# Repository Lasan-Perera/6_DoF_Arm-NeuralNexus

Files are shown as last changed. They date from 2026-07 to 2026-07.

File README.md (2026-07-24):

<div align="center">

# 🦾 NeuralNexus Arm

### A 6-DOF robotic arm built from scratch — mechanics, firmware, kinematics, and a live digital twin.














</div>

---

## 📑 Table of Contents

| # | Section |
|---|---|
| 1 | [Motor Selection](#1--motor-selection) |
| 2 | [Motors, Gearing, Speeds & Joints](#2--motors-gearing-speeds--joints) |
| 3 | [Simulation, IK & Path Planning](#3--simulation-ik--path-planning) |
| 4 | [Mechanical & Electrical Challenges](#4--mechanical--electrical-challenges) |
| 5 | [Hardware Stack](#5--hardware-stack) |
| ➕ | [Software Architecture](#-software-architecture) · [Control Panel](#-web-control-panel) · [Quick Start](#-quick-start) · [Roadmap](#-roadmap) |

---

## 🎯 What This Is

A fully custom 6-axis robotic arm — **not a kit**. Every layer was designed, debugged, and integrated in-house:

```
CAD (SolidWorks)  →  Simscape Multibody twin  →  Inverse Kinematics solver
                                ↓
                     USB CDC @ 115200 baud
                                ↓
              STM32H743 @ 420 MHz  →  6 stepper axes + gripper
                                ↓
                  AS5047P absolute encoders (SPI feedback)
```

**The headline feature:** a single command drives the **physical arm and the 3D digital twin simultaneously**, in sync, in real time.

---

### 🎥 Demos







 
---

## 1. 🔧 Motor Selection

Motor choice was driven by one principle: **torque scales with how much arm you're carrying.** The base carries everything; the wrist carries almost nothing. So the arm uses a *tiered* motor strategy rather than six identical motors.

### Selection Logic

```mermaid
graph TD
    A[Joint torque requirement] --> B{Carries how much<br/>downstream mass?}
    B -->|Base + all links| C[NEMA 23/24<br/>High torque]
    B -->|Wrist only| D[NEMA 17<br/>Low torque, compact]
    C --> E{Positional risk<br/>if steps lost?}
    E -->|Severe| F[Closed-loop driver<br/>CL57T]
    E -->|Moderate| G[Open-loop driver<br/>DM542]
    D --> H[Onboard TMC2209<br/>silent, microstepping]
```

### Why Each Choice

| Tier | Joints | Motor | Reasoning |
|:-----|:---|:---|:---|
| **Heavy** | J2, J3 | **NEMA 24** | Shoulder & elbow lift the entire outboard arm at maximum lever arm. Highest torque demand in the system. |
| **Medium** | J1 | **NEMA 23** | Base rotation carries full mass but works against *inertia*, not gravity — lower continuous torque than the lifting joints. |
| **Light** | J4, J5, J6 | **NEMA 17** | Wrist joints position only the end-effector. Compact size matters more than torque — mass here penalises every joint below it. |

> 💡 **Design insight:** every gram added at the wrist is a gram J2 and J3 must lift at full extension. Motor *mass* is a design constraint, not just torque.

### Driver Pairing

| Driver | Joints | Type | Why |
|:---|:---|:-----|:----|
| **CL57T** | J2, J3 | Closed-loop | Missed steps on the lifting joints = the arm silently drops. Closed-loop drivers detect and correct stalls internally. |
| **DM542** | J1 | Open-loop | Base rotation is more forgiving — a lost step is a heading error, not a collapse. |
| **TMC2209** | J4, J5, J6 | Onboard, silent | Integrated on the custom PCB. Quiet operation, fine microstepping, no external driver boxes for the wrist. |

---

## 2. ⚙️ Motors, Gearing, Speeds & Joints

### Full Drivetrain Map

| Joint | Role | Motor Slot | Motor | Driver | Signal Type | Gear Ratio | Pulses / Joint Rev |
|:---|:-----|:---|:---|:---|:---|:---|:---|
| **J1** | Base rotation | M6 | NEMA 23 | DM542 | Open-drain | **1 : 7** | 2800 |
| **J2** | Shoulder | M4 | NEMA 24 | CL57T | Open-drain | **1 : 30** | 5000 |
| **J3** | Elbow | M5 | NEMA 24 | CL57T | Open-drain | **1 : 30** | 5000 |
| **J4** | Wrist pitch | M2 | NEMA 17 | TMC2209 | Push-pull | **1 : 1** | 6400 |
| **J5** | Wrist roll | M1 | NEMA 17 | TMC2209 | Push-pull | **1 : 1** | 1600 |
| **J6** | End-effector | M3 | NEMA 17 | TMC2209 | Push-pull | **1 : 1** | 1600 |

> ⚠️ **Joints are NOT wired in motor order.** The joint→motor mapping is `jointToMotor[6] = {5, 3, 4, 1, 0, 2}`. This is baked into firmware so every layer above it can think in clean joint numbers (J1…J6, base→tip).

### J2 / J3 Compound Drivetrain

The two lifting joints use a **two-stage reduction** — and where the encoder sits inside that chain turns out to matter enormously (see §4):

```
Motor ──[ 1:10 planetary gearbox ]──► ENCODER ──[ 1:3 belt/pulley ]──► Joint
                                        ▲
                              magnet mounted HERE
                         (3 encoder turns per joint turn)
```

### Joint Limits & Reference Pose

| Joint | Min (°) | Max (°) | Range | Stable Pose (°) | Notes |
|:---|---:|---:|---:|---:|:---|
| J1 | −180 | +180 | 360° | 0 | Full rotation |
| J2 | −70 | +70 | 140° | −5 | Gravity-limited |
| J3 | **+120** | +240 | 120° | **120** | ⚠️ Starts *at* its lower limit — can only move **up** |
| J4 | −180 | +180 | 360° | 0 | Full rotation |
| J5 | +60 | +300 | 240° | 160 | 180°-centred band |
| J6 | −180 | +180 | 360° | 0 | Full rotation |

**Stable reference pose:** `[0, −5, 120, 0, 160, 0]` — the hand-matched starting configuration that keeps the physical arm and the simulation aligned for all relative motion.

### Motion Control Parameters

<table>
<tr><td><b>Control loop</b></td><td>TIM6 ISR @ <b>2 kHz</b> (PSC 74, ARR 499)</td></tr>
<tr><td><b>Tick period</b></td><td>500 µs</td></tr>
<tr><td><b>Max step rate</b></td><td>2000 steps/s (1 step per tick — hard ceiling)</td></tr>
<tr><td><b>Working speed</b></td><td>400 steps/s per joint</td></tr>
<tr><td><b>Acceleration</b></td><td>150 steps/s²</td></tr>
<tr><td><b>Profile</b></td><td>Trapezoidal ramp with decel-to-stop lookahead</td></tr>
</table>

### The Motion Profile

Every axis runs a non-blocking trapezoidal velocity profile inside the ISR — accelerate, cruise, decelerate — computed independently per joint:

```
speed
  ▲
  │     ┌─────────────────┐
  │    ╱                   ╲
  │   ╱                     ╲
  │  ╱                       ╲
  └─┴─────────────────────────┴──► time
    accel        cruise      decel
         (stepsToStop lookahead)
```

> 📐 **The scaling trap:** when the ISR was retuned from 50 kHz → 2 kHz, the hardcoded constants `dt = 0.00002` and `stepInterval = 50000/speed` were **25× wrong**, making every motor crawl. Correct values: `dt = 0.0005`, `stepInterval = 2000/speed`. Tick rate and motion math must always be changed together.

### Command Protocol

| Command | Format | Example | Action |
|:---|:---|:---|:---|
| **Joint move** | 6 comma-separated degrees | `0,-50,60,-80,-90,50` | Relative move on all six joints |
| **Gripper** | `G,<0\|1>` | `G,1` | Open / close servo |
| **Home** | `HOME` | `HOME` | Encoder-based homing (J4/J5/J6) |
| **Test** | `TEST` | `TEST` | 30° encoder calibration measurement |

---

## 3. 🧠 Simulation, IK & Path Planning

### Pipeline

```mermaid
flowchart LR
    A[SolidWorks CAD] -->|export| B[Simscape Multibody]
    B -->|importrobot| C[rigidBodyTree]
    C --> D[inverseKinematics solver]
    E[Target XYZ + orientation] --> D
    D --> F[6 joint angles]
    F --> G[Quintic blend<br/>trajectory]
    G --> H[Mechanics Explorer<br/>3D twin]
    G --> I[USB CDC → STM32<br/>physical arm]
    style H fill:#0076A8,color:#fff
    style I fill:#03234B,color:#fff
```

### Kinematic Model

The CAD assembly exports directly into a **`rigidBodyTree`**, with real joint limits applied so the solver never proposes an unreachable pose:

```matlab
robot = importrobot('Assem1');
robot.DataFormat = 'row';
limitsDeg = [-180 180; -70 70; 120 240; -180 180; 60 300; -180 180];
for i = 1:6
    robot.Bodies{i}.Joint.PositionLimits = deg2rad(limitsDeg(i,:));
end
ik = inverseKinematics('RigidBodyTree', robot);
```

### Trajectory Generation

Paths are interpolated with a **quintic (5th-order) blend** rather than linear interpolation — this gives zero velocity *and* zero acceleration at both endpoints, so motion starts and stops smoothly instead of jerking:

```matlab
b = (k-1)/(steps-1);
blend = 10*b^3 - 15*b^4 + 6*b^5;   % smoothstep: S-curve, C² continuous
pose = startPose + (targetPose - startPose) * blend;
```

### Planned Paths & Demos

| Demo | What It Proves | Method |
|:-----|:---|:---|
| 🎯 **Position Lock** | Tip holds a fixed point in space while the arm reconfigures around it | IK solved for constant XYZ, sweeping orientation |
| 🧭 **Orientation Lock** | Tool orientation stays fixed while the tip sweeps X, then Y, then Z | IK solved for constant rotation matrix, moving XYZ |
| ⬜ **Vertical Square** | Coordinated multi-joint straight-line tracing | 4 corners in the Y–Z plane, edges interpolated, IK per point |
| 👋 **Bye Wave** | Balanced choreography that returns exactly to start | Hand-tuned deltas, every joint column sums to zero |
| 🤖 **Pick & Place** | Full task sequence with gripper actuation | Recorded relative poses + `G,0` / `G,1` |

> 🔬 **A fundamental result we proved (and had to design around):**
>
> **A 6-DOF arm cannot hold tip position AND tool orientation fixed simultaneously while the links reconfigure.** That needs a 7th degree of freedom. Six DOF = exactly six constraints = a unique solution with no redundancy left to exploit. Every "lock" demo therefore locks *one* constraint and varies the other. This wasn't a bug — it's the kinematics telling us the truth.

### Synchronised Twin

The `moveBoth()` function is the centrepiece — one call, two arms:

```matlab
moveBoth(s, [0 10 0 0 0 0])   % J2 +10° on BOTH the real arm and the simulation
```

It tracks accumulated pose in a persistent variable, runs a soft-limit check before committing, streams the delta over serial, and animates the Simscape model — all from a single command.

---

## 4. 🔥 Mechanical & Electrical Challenges

> *This is the section that actually took the time.* Every entry below cost hours of debugging and is documented so it never has to be rediscovered.

### 🥇 The Big One: Phantom Encoder Wander

**Symptom:** encoder readings on a *stationary* joint appeared to swing by **60–70°** between samples. Completely unusable for absolute positioning.

**Failed hypotheses** (each cost a debugging cycle):

| Theory | Test | Result |
|:---|:-----|:---|
| SPI too fast → signal integrity | Slowed prescaler 32 → 64 | Slightly better |
| Still too fast | Slowed further → 128 | ❌ **Got WORSE** |
| ISR corrupting SPI mid-frame | Moved reads to main loop | ❌ No change |

**Actual root cause:** the read function returns **`−1` on a failed read**, and those `−1` sentinels were being **averaged in with valid readings**. A few error codes in a 30-sample mean dragged the average wildly. The sensor was perfect the whole time.

**Fix:** filter `−1` before averaging.

```matlab
if row(j) >= 0            % ← the entire fix
    sums(j) = sums(j) + row(j);
    counts(j) = counts(j) + 1;
end
```

**Result:** readings repeatable to **±0.01°** across runs.

```
BEFORE (raw mean):  J4 = 310.40 → 274.49 → 346.27    (±72° spread) ❌
AFTER  (filtered):  J4 = 181.88 → 181.88 → 181.88    (±0.01°)      ✅
```

> 🧠 **The lesson:** *"slowing it down made it worse"* was the decisive clue. A genuine signal-integrity problem always improves with a slower clock. When it didn't, the problem was never analogue — it was a data-hygiene bug in software.

---

### ⚡ Electrical Failures

<table>
<tr><th align="left">Failure</th><th align="left">Cause</th><th align="left">Resolution</th></tr>
<tr>
<td>💀 <b>3 GPIO pins destroyed</b><br/><code>PE0</code>, <code>PD7</code>, <code>PD3</code></td>
<td>5 V back-feed during miswired open-drain testing — external pull-ups fed 5 V into 3.3 V-tolerant-only pins</td>
<td>Remapped in <code>.ioc</code> → <code>PE7</code>, <code>PD11</code>, <code>PD12</code>. Dead pins left unassigned (Hi-Z). One bodge wire via the <code>M3_MS1</code> pad.</td>
</tr>
<tr>
<td>💀 <b>LDO destroyed</b><br/><code>ST1L05CPU33R</code> (3.3 V rail)</td>
<td>Failed on connection to the main electronics compartment — suspected input overvoltage, inductive transient from the steppers, or insufficient local decoupling</td>
<td><b>Open.</b> Measure actual V<sub>IN</sub> at the LDO footprint <i>before</i> fitting a replacement.</td>
</tr>
</table>

---

### 🔌 The Driver Topology Trap

The custom PCB mixes **two electrically incompatible driver families**, and getting the GPIO mode wrong produces a *silent* failure — no error, the motor just doesn't move.

| | J4 / J5 / J6 (TMC2209) | J1 / J2 / J3 (CL57T · DM542) |
|:--|:--|:--|
| **Mounting** | Onboard | External boxes |
| **GPIO mode** | `OUTPUT_PP` (push-pull 3.3 V) | `OUTPUT_OD` (open-drain) |
| **Wiring** | Direct logic | Common-anode via optocoupler |
| **Enable** | `SetEnableM1M2M3(true)` → LOW | `SetEnableM4M5M6(false)` → **HIGH** |

> ⚠️ **Counter-intuitive but correct:** `Stepper_SetEnableM4M5M6(false)` is what **enables** the external drivers. With common-anode wiring, driving the open-drain pin HIGH releases it (Hi-Z) → opto LED dark → drivers enabled. This looks like a bug in code review. **It is not. Do not "fix" it.**

---

### 🐛 Firmware Bugs Worth Remembering

<details>
<summary><b>Double direction handling</b> — homing only converged from one side</summary>

`Stepper_MoveAllJoints()` applies `jointDir[]` internally. The homing routine *also* computed direction from the measured `encStepSign`. Two sign flips = they cancelled on one side of the target and doubled on the other.

**Fix:** homing and encoder-driven motion must use `Stepper_MoveAll()` — the raw, motor-indexed mover with **no** `jointDir` applied.
</details>

<details>
<summary><b>The unreachable gripper branch</b> — <code>G,0</code> silently did nothing</summary>

```c
if (rxFlag) {
    rxFlag = 0;                    // ← cleared here
    ...
    else if (rxFlag) {             // ← always FALSE. Dead branch.
        if (rxTemp[0] == 'G') { Gripper_Open(); }   // never reached
    }
}
```

The gripper worked perfectly when called directly from the loop — which proved the hardware was fine and pointed straight at command dispatch.

**Fix:** flatten the handler; make the gripper check a top-level `else if`.
</details>

<details>
<summary><b>Off-by-one on joint index</b> — J6 refused to home</summary>

`uint8_t j = 6;` — but joints are indexed **0–5**. J6 is index **5**. Every array access (`homeAngle[6]`, `motors[6]`, `js[6]`) read past the end of its array — undefined behaviour that happened to produce silence instead of a crash.
</details>

<details>
<summary><b>Two infinite loops</b> — commands ignored while encoders streamed</summary>

A leftover `while(1)` encoder-print loop sat *above* the main loop, trapping the CPU forever. The command handler below it was never reached. Symptom looked like "the arm reads encoders but ignores serial" — actually the CPU never got there.
</details>

<details>
<summary><b>Serial handshake deadlock</b> — MATLAB froze mid-demo</summary>

A periodic `enc |` status print flooded the serial line, so MATLAB's `readline() == "END"` handshake never matched → infinite wait, sim and arm both frozen.

**Fix:** telemetry streaming and command handshaking cannot share one wire. Pick one mode at a time, or make the reader tolerant with a timeout.
</details>

---

### ⏱️ The Timing Discovery

**Symptom:** commanding 60° produced only ~30° of motion. Increasing the amplitude didn't help.

**Measurement:** a 60° move physically takes **~4 seconds** at 400 steps/s. The demo scripts were sending the next command after **1 second** — every move was being interrupted at ~25% completion and replaced with a fresh target.

**Solution (user-devised):** never send a move larger than **10°**. Split a 60° move into six 10° commands, each of which completes comfortably within the 1 s window.

```matlab
nChunks   = ceil(max(abs(delta)) / 10);
stepDelta = delta / nChunks;
for c = 1:nChunks
    writeline(s, sprintf('%.2f,%.2f,%.2f,%.2f,%.2f,%.2f', stepDelta));
    pause(1.0);
end
```

> ✅ Elegant because it needs **no firmware change and no handshake** — it just respects the physics of how long a move actually takes.

---

### 🔩 Mechanical: The Simscape Over-Constraint

The imported model wouldn't move at all. Cause: **over-constrained SolidWorks mates**.

| Problem | Effect |
|:---|:---|
| Extra Parallel / Perpendicular mates | Collapsed revolute joints into rigid welds — zero DOF |
| Base mated to non-adjacent links | Created closed kinematic loops the solver couldn't resolve |

**Rule established:** exactly **one concentric + one coincident/distance** mate per joint. Nothing more. Clean serial chain: `Base → P1 → P2 → P3 → P4 → P5 → EndEffector`.

---

### 🧲 The Encoder Mounting Constraint

The most consequential *mechanical* decision in the project — and it was discovered after the fact.

An AS5047P is absolute over **one magnet revolution**. Whether a joint can determine its own position at power-on depends entirely on **what gearing remains between the magnet and the joint**:

```mermaid
graph LR
    A[Encoder magnet] -->|remaining ratio 1:1| B[✅ TRUE ABSOLUTE<br/>one unique reading]
    A -->|remaining ratio 1:N| C[❌ N-fold ambiguity<br/>N poses share a reading]
```

| Joint | Ratio *after* encoder | Absolute on boot? | Consequence |
|:---|:---|:---|:---|
| J1 | 1 : 7 | ❌ | 7 candidate positions per reading |
| J2 | 1 : 3 | ❌ | 3 candidates |
| J3 | 1 : 3 | ❌ | 3 candidates |
| **J4** | **1 : 1** | ✅ | Unique — true absolute |
| **J5** | **1 : 1** | ✅ | Unique — true absolute |
| **J6** | **1 : 1** | ✅ | Unique — true absolute |

**Workaround in use:** hand-position the arm *roughly* near home, then command `HOME`. Pre-positioning within one encoder revolution removes the ambiguity entirely, letting the encoder resolve the fine error. Clever, free, and it works today.

**Permanent fix (future revision):** relocate the J1/J2/J3 magnets to the *joint side* of the final reduction. All six joints then become absolute and the whole problem disappears.

---

### 💻 Host-Side Gotchas

| Issue | Symptom | Fix |
|:---|:---|:----|
| **USB CDC won't enumerate** | Device Manager shows nothing / "Unknown Device" | Route **HSI48** to USB clock + call `HAL_PWREx_EnableUSBVoltageDetector()` **before** `MX_USB_DEVICE_Init()` |
| **Board freezes at boot** | No LED, no USB, totally dead | `MX_SDMMC1_SD_Init()` traps in `Error_Handler()` with no SD card. Keep SDMMC1 + FATFS **disabled in the `.ioc`** |
| **COM port keeps changing** | COM9 → COM12 → COM14… | Windows caches stale USB devices. Device Manager → *Show hidden devices* → uninstall greyed entries → replug |
| **`importrobot` fails** | "Variable `jointData` has been deleted" | Simscape *From Workspace* blocks are evaluated during import. Run `jointData = zeros(2,7);` **first** |
| **Timer resource conflict** | Gripper twitched whenever the buzzer sounded | Both were on TIM2. `Buzzer_SetFreq()` reprograms PSC/ARR, destroying the servo's 50 Hz frame. **Moved gripper to TIM1_CH3** — conflict eliminated |

---

## 5. 🛠️ Hardware Stack

### Compute

| Component | Spec |
|:---|:-----|
| **MCU** | STM32H743VITx, Cortex-M7 |
| **Clock** | 420 MHz (25 MHz HSE → PLL) |
| **PCB** | Custom board (migrated from WeAct MiniSTM32H743 dev board) |
| **Toolchain** | STM32CubeIDE + CubeMX (HAL) |

### Actuation

| Component | Detail |
|:---|:---|
| **Steppers** | 2× NEMA 24 · 1× NEMA 23 · 3× NEMA 17 |
| **Closed-loop drivers** | 2× CL57T (J2, J3) |
| **Open-loop driver** | 1× DM542 (J1) |
| **Onboard drivers** | 3× TMC2209 (J4, J5, J6) |
| **Gripper** | Hobby servo · TIM1_CH3 · 50 Hz PWM · 930 µs open / 1100 µs close |

### Sensing

| Component | Detail |
|:---|:---|
| **Encoders** | 6× AS5047P magnetic absolute, 14-bit (16384 counts/rev) |
| **Bus** | SPI1 — 16-bit frames, CPOL HIGH / CPHA 2EDGE (mode 1) |
| **Chip selects** | `PB0` `PB1` `PB2` `PC7` `PC6` `PD15` (active-LOW) |
| **Noise floor** | ±0.04° at rest (after `−1` filtering) |

### Peripherals & I/O

| Function | Resource |
|:---|:---|
| Stepper control loop | TIM6 @ 2 kHz interrupt |
| Gripper servo PWM | TIM1_CH3 |
| Buzzer | TIM2_CH2 / PA1 |
| Host link | USB CDC Virtual COM @ 115200 |
| Status | Onboard LED, user buttons |

### Peripheral Allocation

```
TIM1 ─── CH3 ──► Gripper servo PWM (50 Hz)
TIM2 ─── CH2 ──► Buzzer (variable frequency)
TIM6 ─────────► Stepper ISR @ 2 kHz  ◄── the heartbeat
SPI1 ─────────► AS5047P encoder chain ×6
USB  ─────────► CDC Virtual COM Port
```

> 🧯 **Peripheral conflicts are real.** The gripper and buzzer originally shared TIM2 and were mutually exclusive — playing a tone corrupted the servo signal. Separating them onto different timers was a genuine architectural fix, not cosmetic.

---

## 🏗️ Software Architecture

```mermaid
graph TB
    subgraph HOST["🖥️ Host Layer"]
        M[MATLAB<br/>IK · Simscape twin]
        W[Web Control Panel<br/>Web Serial API]
    end
    subgraph FW["⚙️ STM32 Firmware"]
        P[Command Parser]
        S[Stepper_MoveAllJoints<br/>joint-indexed + jointDir]
        R[Stepper_MoveAll<br/>raw motor-indexed]
        I[TIM6 ISR @ 2 kHz<br/>trapezoidal profile]
        E[Encoder read + tick accumulate]
        H[Home_All · Encoder_Test30]
    end
    subgraph HW["🦾 Hardware"]
        D[6× Stepper drivers]
        G[Gripper servo]
        A[6× AS5047P]
    end
    M -->|USB CDC| P
    W -->|USB CDC| P
    P --> S
    P --> G
    P --> H
    H --> R
    S --> I
    R --> I
    I --> D
    I --> E
    A --> E
    E --> H
    style I fill:#c62828,color:#fff
    style M fill:#0076A8,color:#fff
    style W fill:#f7df1e,color:#000
```

### Two Movers, One Critical Distinction

| Function | Indexing | Applies `jointDir`? | Use for |
|:---|:---|:---|:---|
| `Stepper_MoveAllJoints()` | **Joint** (J1…J6) | ✅ Yes | Commands from MATLAB / UI |
| `Stepper_MoveAll()` | **Motor** (M1…M6) | ❌ No | Homing & encoder-driven correction |

> ☝️ Mixing these up causes the **double-direction bug** — the single most time-consuming class of error in this project. Encoder feedback already knows the true physical direction via `encStepSign`; applying `jointDir` on top of it inverts the correction on one side of the target.

---

## 🎛️ Web Control Panel

A standalone **Web Serial** control panel that talks to the arm directly — **no MATLAB, no Python, no install.** Just open the HTML file in Chrome or Edge.

```
┌──────────────────────────────────────────────┐
│ 🔌 Connect arm      ● Connected       ■ Stop │
├──────────────────────────────────────────────┤
│  RECORDED SEQUENCES               Delay [4]s │
│  ┌──────────┬──────────┬───────────────────┐ │
│  │ Show off │   Pick   │ Place from pole   │ │
│  ├──────────┼──────────┴───────────────────┤ │
│  │Pick pole │  Pick and place pole         │ │
│  └──────────┴──────────────────────────────┘ │
├──────────────────────────────────────────────┤
│  JOINT CONTROL — relative move               │
│  J1 ─────────────●─────────────   0°         │
│  J2 ─────────────●─────────────   0°         │
│  J3 ─────────────●─────────────   0°    …    │
│           [ Send move ]   [ Reset ]          │
├──────────────────────────────────────────────┤
│  [ Open ]   [ Close ]   [ Home ]             │
│  > 0,-50,60,-80,-90,50            [ Send ]   │
└──────────────────────────────────────────────┘
```

| Feature | Detail |
|:---|:---|
| **Transport** | Web Serial API @ 115200 — direct browser-to-MCU |
| **Sequences** | All five recorded motions as one-click buttons |
| **Jog control** | Six centred sliders (−90° … +90°), sent as one relative move |
| **Safety** | Stop button cancels a running sequence mid-flight |
| **Live log** | Timestamped record of every command sent |

> 🌐 **Why this matters for a finished product:** the demo machine no longer needs a MATLAB licence. MATLAB remains the *authoring* environment (IK, trajectory design, the digital twin) — the browser is the *operator* interface.

---

## 🚀 Quick Start

### Firmware

```bash
# 1. Open the project in STM32CubeIDE
# 2. If regenerating from CubeMX, re-comment MX_SDMMC1_SD_Init()  ← it traps without an SD card
# 3. Build (🔨) and flash via ST-Link (▶)
# 4. Confirm the board enumerates as a USB Virtual COM Port
```

### MATLAB Session

```matlab
jointData = zeros(2,7);              % MUST come first — From Workspace blocks need it
load_system('Assem1');
robot = importrobot('Assem1');  robot.DataFormat = 'row';

limitsDeg = [-180 180; -70 70; 120 240; -180 180; 60 300; -180 180];
for i = 1:6
    robot.Bodies{i}.Joint.PositionLimits = deg2rad(limitsDeg(i,:));
end

ik = inverseKinematics('RigidBodyTree', robot);
weights = [1 1 1 1 1 1];
q0 = homeConfiguration(robot);
s  = serialport("COM9", 115200);     % update port as needed
```

### Everyday Commands

```matlab
armIK(robot, ik, weights, q0)                            % interactive IK slider tool
goToXYZ(robot, ik, weights, q0, [-0.15 0.30 0.10], s)    % XYZ → arm + synced twin
moveBoth(s, [0 10 0 0 0 0])                              % relative move on BOTH
armWave(s)                                               % goodbye choreography
objectPicking(s)                                         % pick sequence
writeline(s, "HOME")                                     % encoder homing
```

### Browser Panel

```
1. Close the MATLAB port first:  clear s
2. Open NeuralNexusArmControl.html in Chrome / Edge
3. Click "Connect arm" → select the COM port
4. Drive it.
```

---

## 📊 Project Status

| Subsystem | Status | Notes |
|:---|:---:|:---|
| 6-axis stepper control | ✅ | Trapezoidal profile, 2 kHz ISR |
| USB CDC command link | ✅ | 115200, parsed & verified |
| Joint mapping | ✅ | `jointToMotor` verified on hardware |
| Direction signs | ✅ | `jointDir` verified via A/B sim-vs-hardware |
| MATLAB IK pipeline | ✅ | `rigidBodyTree` + solver + limits |
| Synchronised digital twin | ✅ | `moveBoth()` — arm & sim in lockstep |
| Gripper servo | ✅ | TIM1_CH3, serial-commanded |
| Encoder read (AS5047P) | ✅ | ±0.01° repeatable after `−1` filtering |
| Recorded motion library | ✅ | 5 sequences + wave + square |
| Web control panel | ✅ | Web Serial, MATLAB-free |
| Homing — J4 / J5 / J6 | 🟡 | Works; scaling verification ongoing |
| Homing — J1 / J2 / J3 | 🔴 | Blocked by encoder mounting ratio |
| `pulsesPerJointRev` calibration | 🟡 | J6 measured at 3200 (not 1600) — others pending |
| Absolute positioning | 🟡 | Viable for the 1:1 wrist joints |
| 3.3 V LDO replacement | 🔴 | Measure V<sub>IN</sub> before fitting |
| Closed-loop step correction | ⚪ | Planned |
| Vision pick-and-place | ⚪ | Planned |

---

## 🗺️ Roadmap

```mermaid
gantt
    title Development Phases
    dateFormat X
    axisFormat %s
    section Complete
    Simscape model fix        :done, 0, 1
    MATLAB IK pipeline        :done, 1, 2
    STM32 6-axis firmware     :done, 2, 3
    Encoder integration       :done, 3, 4
    Synced twin and demos     :done, 4, 5
    Web control panel         :done, 5, 6
    section In Progress
    Per-joint calibration     :active, 6, 7
    Absolute positioning      :active, 7, 8
    section Planned
    Closed-loop correction    :8, 9
    Encoder remount J1-J3     :9, 10
    Vision pick-and-place     :10, 11
```
---

# 👁️ Computer Vision & Object Detection











> **The eyes of the NeuralNexusArm.** This subsystem turns raw camera pixels into real-world `(X, Y)` coordinates that feed straight into the inverse kinematics solver — closing the loop between *seeing* and *reaching*.

---

## 🔁 Pipeline Overview

```mermaid
flowchart LR
    A([📷 Camera Feed]) --> B[🧹 Undistort<br/>Camera + Distortion Matrix]
    B --> C{🎯 Detection Mode}
    C -->|Primary| D[🎨 OpenCV<br/>Colour Segmentation]
    C -->|Fallback| E[🧠 Trained Models<br/>YOLO / Custom]
    D --> F[📍 Object Centroid<br/>in pixels]
    E --> F
    F --> G[🗺️ Homography<br/>Pixel → World mm]
    G --> H([🦾 IK Solver → Arm Motion])

    style A fill:#1f77b4,stroke:#fff,color:#fff
    style D fill:#2ca02c,stroke:#fff,color:#fff
    style E fill:#9467bd,stroke:#fff,color:#fff
    style G fill:#ff7f0e,stroke:#fff,color:#fff
    style H fill:#d62728,stroke:#fff,color:#fff
```

---

## Object Detection

### Primary — OpenCV Colour Identification

The main detection path uses **classical colour segmentation** (HSV thresholding → contour extraction → centroid).

Why classical over learned, as the default?

| Latency | Determinism | Compute | Tunability |
|:---:|:---:|:---:|:---:|
| Millisecond-scale | Same input → same output, every time | Runs comfortably on CPU | Live HSV slider tuning |

### Secondary — Trained Detectors

For objects that colour alone cannot separate, the repository also ships learned detectors:

| Model | Target | Type |
|---|---|:---:|
| 📦 Custom trained | Cardboard box detection |  |
| 🍬 Custom trained | Candy detection |  |
| `yolo26n.pt` | General-purpose objects |  |
| `yolo11n.pt` | General-purpose objects |  |

---

## Camera Calibration

Calibration runs in **two independent stages** — first fix the *camera*, then fix the *world*.

```mermaid
flowchart TB
    subgraph S1["🔬 Stage 1 — Intrinsic"]
        A1[♟️ 20 Chessboard Images] --> A2[Camera Matrix]
        A1 --> A3[Distortion Coefficients]
        A2 --> A4[✅ Reprojection Error<br/>0.6863 px]
        A3 --> A4
    end
    subgraph S2["🌍 Stage 2 — Extrinsic"]
        B1[📏 Fixed Mount @ 41 cm] --> B2[Known World Points]
        B2 --> B3[3×3 Homography Matrix]
        B3 --> B4[✅ Pixel → mm Mapping]
    end
    S1 --> S2

    style A4 fill:#2ca02c,stroke:#fff,color:#fff
    style B4 fill:#2ca02c,stroke:#fff,color:#fff
```

### ♟️ Stage 1 — Chessboard Calibration *(Intrinsic)*

Standard OpenCV chessboard calibration recovers two matrices:

<table>
<tr>
<td width="50%">

**🔭 Camera Matrix**

Describes the camera's *own* optical properties:
- Focal lengths `fx`, `fy`
- Principal point `cx`, `cy`

</td>
<td width="50%">

** Distortion Coefficients**

Model and cancel lens distortion:
- Radial (barrel / pincushion)
- Tangential (sensor misalignment)

</td>
</tr>
</table>

**Method** — 20 chessboard images captured at varying angles, orientations, and positions across the frame.

<!-- Rendered as a green "Tip" callout on GitHub -->
> [!TIP]
> **Result: mean reprojection error = `0.6863 px`** — comfortably sub-pixel, which is a healthy calibration for a 20-image set.

### Stage 2 — Homographic Calibration *(Pixel → World)*

With the camera **rigidly mounted at a fixed height**, a single `3×3` homography maps undistorted pixel coordinates to real-world planar coordinates in the arm's base frame.

Because the pose is fixed and every target lies on one plane (the table surface), **no per-frame depth estimation is required** — one matrix does the whole job.

```
┌─────────────────────────────────────────┐
│   📷  Camera                            │
│    │                                    │
│    │  ↕  Fixed height = 41 cm           │
│    │                                    │
│  ══╧══════════════════════════════════  │  ← Work surface (Z = 0)
│      🎯 Targets live on this plane      │
└─────────────────────────────────────────┘
```

<!-- Rendered as a red "Warning" callout on GitHub -->
> [!WARNING]
> The homography is valid **only** for this exact mounting height and pose. Move or re-aim the camera and the homographic calibration **must be redone** — the intrinsic calibration, however, stays valid.

---

<div align="center">

### 📂 Repositories




---
</div>

## 👥 Team
 
| Index No. | Name | GitHub |
|:---|:-----|:---|
| **230487D** | Lasan Perera | [@Lasan-Perera](https://github.com/Lasan-Perera) |
| **230502X** | Deneth Priyadarshana | — |
| **230492M** | Dulana Pitiwaduge | [@DulanaPiti](https://github.com/DulanaPiti) |
| **230051L** | Isitha Dinujaya | — |
| **230108U** | Mokshan Colombage | — |
 
---

<!-- ## License -->
<!-- Add a license here (e.g. MIT) if you want others to reuse the code. -->

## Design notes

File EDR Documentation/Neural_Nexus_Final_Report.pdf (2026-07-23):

University of Moratuwa: Electronic Design Realization

# NEURAL NEXUS

## Advanced 6-DOF Robotic & AI Ecosystems for Precision Automation

### Team Neural Nexus

### Lasan Perera 230487D Isitha Dinujaya 230051L Deneth Priyadarshana 230502X Dulana Pitiwaduge 230492M Mokshan Colombage 230018U

### July 19, 2026

Abstract

The global industrial robotics market is experiencing unprecedented growth, yet advanced 6-Degree-of-Freedom (DOF) robotic arms remain prohibitively expensive for Small and Medium Enterprises (SMEs) in developing nations like Sri Lanka. This report details the technical development, business strategy, and commercialization roadmap of Neural Nexus: an affordable, high-precision 6-DOF robotic arm engineered for localized manufacturing. Utilizing a distributed control architecture, the system currently employs standard terminal interfaces for command routing, with a dedicated touch-enabled Human-Machine Interface (HMI) slated as a premium future add-on. A sophisticated MATLAB-based Digital Twin leverages a dedicated Inverse Kinematics (IK) model for complex trajectory simulation and collision validation, mitigating operational risks. The validated spatial coordinates are subsequently executed by a custom PCB built around an STM32H743VIT6 Master Control Unit (MCU), which drives all six axes and closes the position loop using AS5047P magnetic absolute encoders read over SPI on every joint. At a total project value of approximately 568,982.27 LKR and a strategic retail price of 1,500,000 LKR, this ecosystem undercuts imported alternatives by over 25–33% while maintaining industrial-grade performance, offering local SMEs a highly lucrative, rapid-ROI pathway to Industry 4.0 automation.

# Contents

1 Problem Description, Motivation, and Justification | 1
2 Technical Feasibility and Design for Manufacturability (DFM) | 5
3 Product Architecture | 7
4 PCB Design | 10
5 Product Enclosures and Sketches | 19
6 Final Product Details and Operational Value | 27
7 Manufacturing Considerations (Volume Production) | 31

i

8 Costing, Pricing Strategy, and Customer ROI | 32
9 Marketing, Sales, and Beyond | 34
10 Project Budget and Bill of Quantities (BOQ) | 37
11 Task Allocation Among Group Members | 40

ii

# Chapter 1

# Problem Description, Motivation, and Justification

## 1.1 The Market Gap and Macroeconomic Drivers

The global market for industrial robotics is projected to escalate from $1.2 billion in 2023 to $10.5 billion by 2030, representing a Compound Annual Growth Rate (CAGR) of 36%. Concurrently, post-pandemic supply chain disruptions and persistent labor shortages have driven a 28% increase in Small and Medium Enterprise (SME) automation adoption globally. However, in developing markets like Sri Lanka, a critical market failure exists driven by severe macroeconomic factors. Severe foreign exchange fluctuations (most recently during the 2022 balance-of-payments crisis), high import taxation, and extended shipping delays (often 6 to 8 months) drastically inflate the landed cost of capital machinery. Currently, entry-level industrial 6-DOF arms cost between $15,000 and $80,000 upfront. Once imported, this Capital Expenditure (CAPEX) becomes entirely inaccessible to local SMEs and academic laboratories, stifling industrial modernization and economic growth.

## 1.2 Local Market Context: Sri Lanka

Beyond the global figures above, several Sri Lanka-specific indicators sharpen the case for a locally manufactured arm:

- SMEs are the backbone of the local economy. Small and Medium Enterprises account for over 75% of all active businesses in Sri Lanka, contribute approximately 52% of GDP, and provide around 45% of national employment. Within the manufacturing sector specifically, small and medium-scale industries make up roughly 96% of industrial units and about 36% of industrial employment—meaning the vast majority of Sri Lanka’s manufacturing base is precisely the CAPEX-constrained customer segment Neural Nexus targets, rather than a handful of large conglomerates.
- The import duty structure compounds against capital machinery. Imports into Sri Lanka are subject to a stacked tax structure: an 18% Value Added Tax (VAT), a 7.5% Ports and Airports Development Levy (PAL), and a 2.5% Social Security

Contribution Levy (SSCL), applied cumulatively on top of any applicable Customs Import Duty, with VAT calculated last on the full duty-inclusive value. Even where capital machinery qualifies for a concessionary customs duty rate, the PAL/SSCL/VAT stack alone typically adds on the order of 25–30% to the landed cost, on top of freight, insurance, and clearance charges—directly corroborating the CAPEX inflation problem described above.

- Rising local labor costs strengthen the automation ROI case. Wage inflation in Sri Lanka’s manufacturing sector, alongside statutory contributions (EPF/ETF) and overtime premiums, makes repetitive-task automation an increasingly attractive OPEX trade-off for local factory owners, reinforcing the ROI case built in Chapter 8.
- Local demand for robotics education already exists—supply does not. Multiple Sri Lankan universities (including the University of Moratuwa, SLIIT, the Open University of Sri Lanka, and CINEC Campus) already run dedicated Mechatronics or Robotics and Automation degree programmes, confirming strong latent academic demand. However, based on our review of publicly available laboratory facilities, none of these programmes currently have hands-on access to a locally supported, industrial-grade, programmable 6-DOF arm; robotics and automation modules are taught predominantly through simulation software or small hobbyist-grade kits, since the same import-cost barrier described above applies equally to educational procurement budgets. This is the specific gap Neural Nexus’s education bundle (Chapter 9) is designed to fill.
- The local STEM education market is growing quickly, and pre-university demand is already commercial. STEM enrolment across selected Sri Lankan higher education institutions grew at roughly 10% per year between 2017 and 2023 under the World Bank-backed AHEAD higher-education reform programme, well ahead of the programme’s original target. Below the university level, a maturing ecosystem of private robotics and coding academies (e.g. STEM.org-affiliated centres, dedicated kids’ robotics institutes, and project-based STEM labs) is already operating profitably across the country, teaching robotics predominantly with imported hobbyist kits—evidence that Sri Lankan families and institutions are already paying for STEM/robotics instruction, just not yet on industrial-grade hardware.

## 1.3 Market Evidence Summary

The table below consolidates the market and survey indicators that motivate this project, combining global industry figures with the Sri Lanka-specific data above. These figures were gathered from industry growth reports, Sri Lanka Customs’ published tariff schedule, national wage statistics, and a review of local university engineering programmes, and are used as supporting evidence for the problem statement rather than a definitive market study.

Indicator | Value
Entry-level imported 6-DOF arm cost | $15,000 – $80,000
Global industrial robotics market (2023) | $1.2 billion
Global industrial robotics market (2030, projected) | $10.5 billion
Market CAGR (2023–2030) | 36%
Increase in SME automation adoption post-pandemic | 28%
Global STEM robotics education market (2024) | $2.8 billion
Sri Lankan SME contribution to GDP | ∼52%
Sri Lankan SME share of active enter- prises | >75%
Small/medium-scale industry share of manufacturing units (LK) | ∼96%
Combined import levy stack on capital machinery (PAL+SSCL+VAT) | ∼25–30%
Sri Lankan universities offering mecha- tronics/robotics degrees (identified) | 4+
Of those, with hands-on lab access to a programmable 6-DOF arm | 0
Sri Lanka STEM higher-education enrol- ment growth (2017–2023) | ∼10%/year
Typical import lead time for capital ma- chinery | 6–8 months

Table 1.1: Key global and Sri Lanka-specific market indicators supporting the Neural Nexus problem statement

The combination of a fast-growing global market, a structurally CAPEX-constrained local SME manufacturing base, a compounding local import-tax burden, rising local labor costs, and unmet local demand for hands-on robotics education together form the central justification for this project.

## 1.4 Justification for Selection and Value Proposition

While low-cost, hobbyist-grade robotic alternatives exist on the market, they universally sacrifice precision, payload capacity, and software ecosystem capabilities, rendering them useless for industrial compliance. Currently, no reliable, locally supported mid-tier solution exists that offers sub-millimeter repeatability at an accessible price point. Furthermore, as shown above, no Sri Lankan engineering faculty currently has hands-on access to a programmable 6-DOF arm for STEM curriculum, despite several of them already running dedicated mechatronics and robotics degree programmes (a global educational market valued at $2.8B in 2024).

By developing Neural Nexus—a locally manufactured, high-precision robotic arm—we aggressively penetrate this unserved mid-tier market. Our primary value proposition is delivering industrial-grade automation that drastically lowers the capital barrier to entry for local SMEs, completely bypasses severe import delays, and provides the localized, zero-downtime technical support that foreign competitors fundamentally lack.

# Chapter 2

# Technical Feasibility and Design for Manufacturability (DFM)

The Neural Nexus project is highly technically feasible. All resource requirements and performance targets are reachable using a strategic combination of locally sourced materials, optimized electronic configurations, and a strong emphasis on Design for Manufacturability (DFM).

## 2.1 Cost-to-Performance Optimization in Hardware

To achieve industrial repeatability without relying on prohibitively expensive $2,000 servo motors, the mechanical structure utilizes rigid aluminum structural components paired with custom 3D-printed parts. This hybrid material approach provides superior structural rigidity under dynamic loads, excellent heat dissipation, and eliminates flex over the 800mm lever arm, all while keeping chassis fabrication costs exceptionally low and insulated from global supply chain shocks.
For actuation, we utilize a highly calibrated combination of open-loop and closed-loop NEMA stepper motors (NEMA 17, 23, and 24). Paired with TMC2209 and CL57T drivers, this drive-train achieves the extreme microstepping required for precise sub-millimeter repeatability. By utilizing closed-loop steppers on the critical load-bearing joints, we guarantee position retention and eliminate step-loss without the exorbitant costs associated with traditional industrial servos, keeping our Cost of Goods Sold (COGS) strictly within budget.

## 2.2 Control and Software Feasibility

Beyond the mechanical drive-train, feasibility depends on the reliability of the control and software stack:

- Kinematics: The MATLAB Digital Twin uses established closed-form and iterative IK solvers (Robotics System Toolbox) that are well within MATLAB’s proven capability envelope for a 6-DOF serial-link manipulator, so no unproven algorithmic risk is carried on the critical path.

- Firmware: The STM32H743VIT6 (Arm Cortex-M7, up to 480 MHz) has more than sufficient timer, PWM, and SPI resources to generate jitter-free step/direction pulses for six axes simultaneously while polling six SPI-connected absolute encoders for closed-loop position feedback, well inside its documented real-time performance envelope.
- Computer Vision: Object detection and pose estimation run on standard camera hardware using established, pre-trained model architectures, avoiding the need for bespoke model development on the critical path.

## 2.3 Resource Availability and Procurement Feasibility

All electromechanical components (NEMA motors, TMC2209/CL57T drivers, aluminum stock, fasteners, bearings) are available from local or regional (South/South-East Asian) suppliers with lead times of days to a few weeks, rather than the 6–8 month lead times faced by fully assembled imported arms. This significantly de-risks the project schedule and insulates the Bill of Materials (BOM) from long-haul shipping disruptions.

## 2.4 Performance Target Validation

Target Metric | Design Target Feasibility Basis
Repeatability | Sub-millimeter | Closed-loop steppers + microstepping drivers
Payload capacity 2 kg | Torque-matched NEMA 17/23/24 selection
Reach | 800 mm | Aluminum link rigidity validated against flex limits
Duty cycle | 24/7 continuous Mains-powered, no battery degradation constraint

Table 2.1: Mapping of design targets to feasibility basis

# Chapter 3

# Product Architecture

Neural Nexus utilizes a highly modular, distributed control architecture to separate high-level trajectory planning from low-level deterministic motor control, ensuring maximum system stability, scalability, and safety.

## 3.1 System Block Diagram

Figure 3.1 shows the four functional blocks of the system and the direction of data flow between them: command input and simulation (currently PC-terminal driven, with a touch HMI as a future add-on), the MATLAB Digital Twin, the STM32H743VIT6-based real-time firmware, and the physical hardware, with a dashed feedback path returning per-axis absolute encoder position data back up the chain over a dedicated SPI bus.

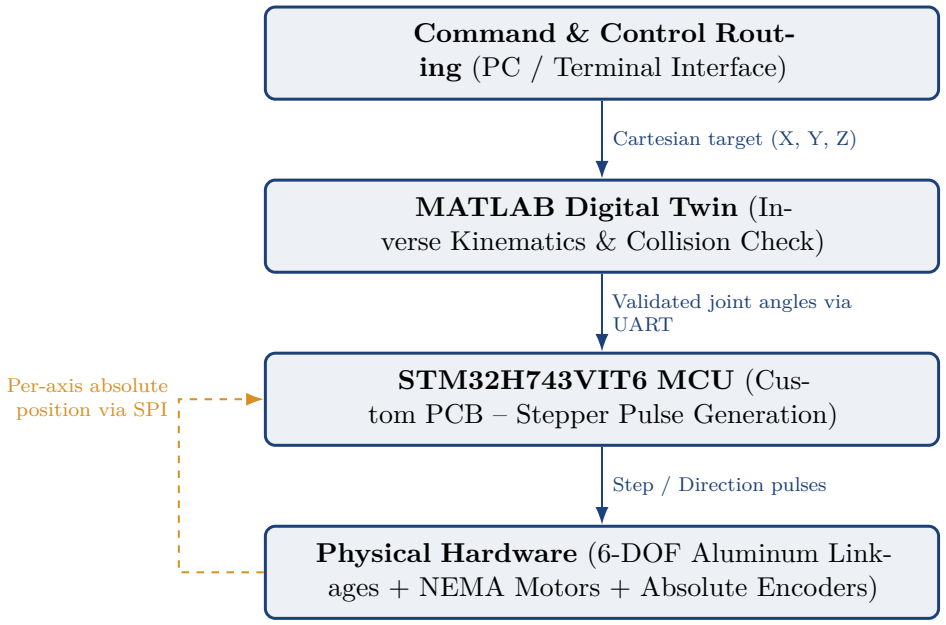
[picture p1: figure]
Command & Control Rout- ing (PC / Terminal Interface); MATLAB Digital Twin (In- verse Kinematics & Collision Check); STM32H743VIT6 MCU (Cus- tom PCB – Stepper Pulse Generation); Physical Hardware (6-DOF Aluminum Link- ages + NEMA Motors + Absolute Encoders); Cartesian target (X, Y, Z); Validated joint angles via UART; Step / Direction pulses; Per-axis absolute position via SPI

Figure 3.1: Neural Nexus distributed control architecture: command flow (solid) and real-time SPI encoder feedback (dashed).

## 3.2 Block Descriptions

- Command & Control Routing: Currently, user Cartesian targets (X, Y, Z) and operational commands are routed via standard tethered PC interfaces directly into the computational engine. (Note: A dedicated, physical touch-screen HMI console is planned as a premium, monetizable add-on for enterprise clients, detailed in Chapter 9).
- Trajectory Simulation (MATLAB Digital Twin): The core kinematic calculations have been strategically offloaded to a MATLAB-based Digital Twin, acting as the system’s heavy computational engine. This environment runs a sophisticated Inverse Kinematics (IK) model to simulate complex trajectories, verify joint limits, and ensure collision avoidance. From a business perspective, this acts as a critical risk-mitigation tool, preventing costly hardware collisions on the factory floor before any physical motion is executed.
- Real-Time Edge Firmware (STM32H743VIT6, Custom PCB): Once validated by the Digital Twin, spatial coordinates are streamed via high-speed UART to a bespoke control board built around an STM32H743VIT6 microcontroller (Arm Cortex-M7 core, up to 480 MHz, 2 MB Flash, 1 MB RAM, LQFP-100 package). The MCU acts as the deterministic execution layer, translating the calculated joint angles into jitter-free stepper pulses on its dedicated motor-control timer channels. In parallel, it polls a dedicated SPI bus to read back absolute position data from a AS5047P magnetic absolute encoder mounted on each of the six axes, closing the position loop entirely on-board without relying on the host PC or the Digital Twin for real-time feedback. The Cortex-M7’s headroom (well above what six simultaneous step-pulse trains and six polled SPI encoder channels require) leaves comfortable margin for future features such as on-board safety interlocks or local trajectory smoothing.
- Physical Hardware: The execution layer consists of the 6-DOF aluminum linkages driven by the NEMA stepper array, with each axis fitted with a AS5047P magnetic absolute encoder that reports true joint position back to the STM32H743VIT6 over SPI, independent of step-count tracking.

## 3.3 Deviations from Original Plan

Initially, the Digital Twin and Inverse Kinematics calculations were planned to be executed entirely on a Raspberry Pi edge device. However, during development, we determined that simulating complex 6-DOF kinematics required more robust computational modeling to guarantee industrial safety and precision.
Strategic Pivot: We transitioned the Digital Twin and core IK modeling to run natively on MATLAB. This deviation was highly successful. MATLAB’s extensive kinematics libraries allowed for far superior trajectory smoothing, error-checking, and visualization compared to our initial embedded approach, resulting in a much more reliable and robust end-product for the consumer.

Interim Mid-Evaluation Architecture: At the mid-evaluation stage, the demonstrator used a fully integrated touch-screen HMI performing on-edge IK directly on a generic STM32 development board alongside the UART/USB control link, to showcase the end-to-end concept on a single self-contained rig. Following the pivot above, the finalized architecture deliberately separates these responsibilities: IK and collision-checking now run on the more computationally capable MATLAB Digital Twin rather than on the MCU, and the touch HMI has been repositioned from a standard included component to a premium add-on (Chapter 9), which also simplifies the base unit’s cost structure without removing the option for enterprise customers.
MCU and Feedback Upgrade: The generic development-board STM32 used at mid-evaluation was replaced with a custom PCB built around the STM32H743VIT6, selected for its higher timer count, larger SRAM/Flash headroom, and larger number of hardware SPI peripherals. This directly enabled the second key hardware deviation: swapping simple limit-switch-only feedback for per-motor AS5047P magnetic absolute encoders read over SPI, giving true closed-loop joint-position awareness on every axis (rather than only end-of-travel detection), which is what ultimately underpins the sub-millimeter repeatability target validated in Chapter 2.

# Chapter 4

# PCB Design

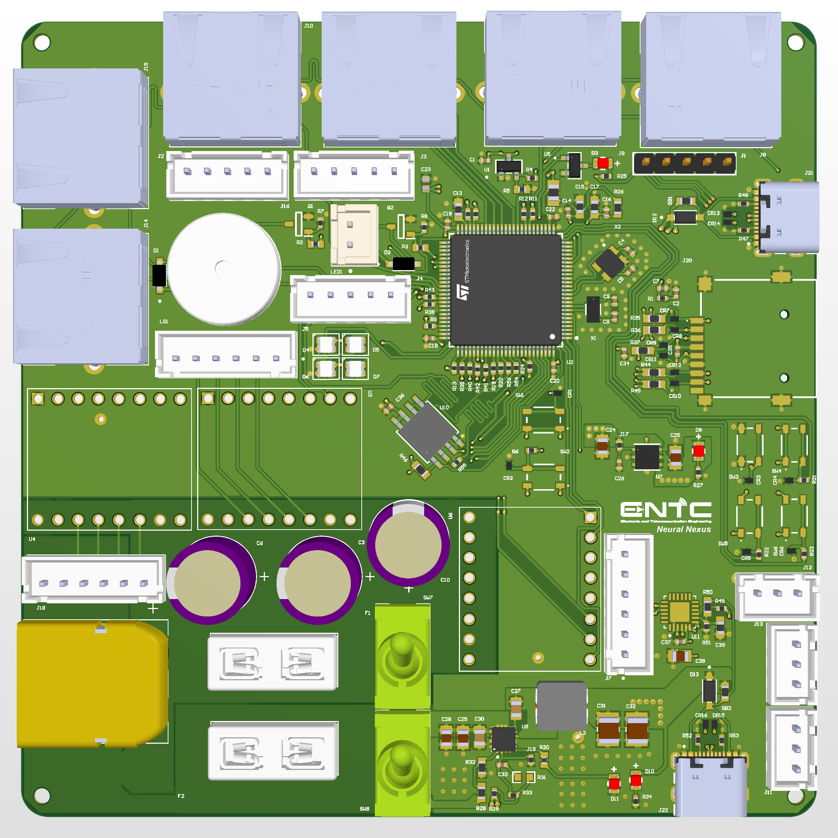
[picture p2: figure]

Figure 4.1: Neural Nexus custom control board — 3D render, top (component) side. The STM32H743VIT6 MCU is visible at center, flanked by the RJ-connector bank for the six per-axis SPI absolute encoder / motor driver harnesses (top), USB-C and barrel power input (right), and status LEDs / user switches (bottom right).

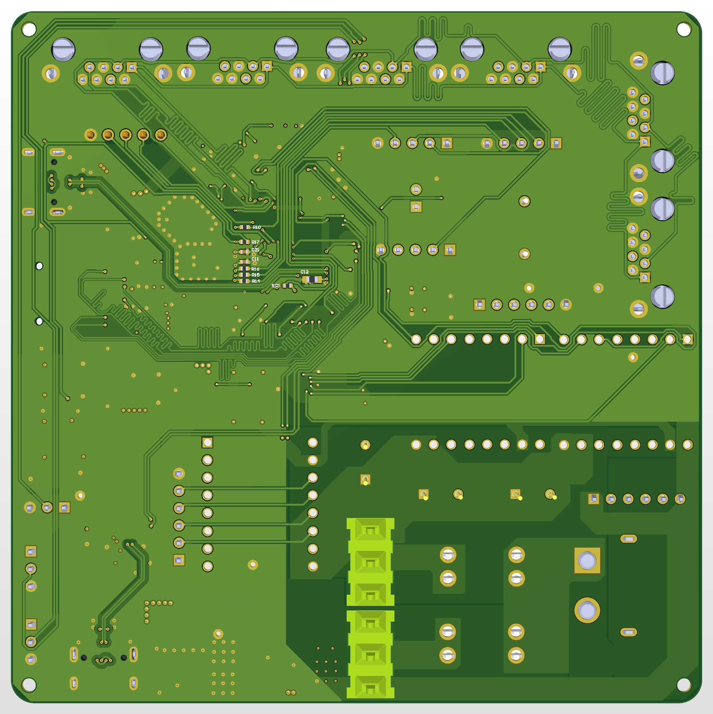
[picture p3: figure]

Figure 4.2: Neural Nexus custom control board — 3D render, bottom (routing) side, showing the high-current motor driver copper pours (bottom right, highlighted) kept physically separated from the logic and SPI routing above them.

## 4.1 Master Control Unit (MCU): STM32H743VIT6

The custom PCB is built around an STM32H743VIT6 as the Master Control Unit (MCU), replacing the generic development board used at the mid-evaluation stage. As shown in Figure 4.1, the MCU is placed centrally on the board with the six RJ-style motor/encoder harness connectors run along the top edge, minimizing average trace length from the MCU’s SPI and timer pins to each axis connector. Key selection and layout considerations:

- Compute headroom: The Arm Cortex-M7 core (up to 480 MHz, with FPU and DSP extensions) comfortably services six simultaneous hardware-timer step/direction pulse trains while concurrently polling six SPI encoder channels, and provides the floating-point math throughput needed to support on-board inverse-kinematics routines, with substantial margin left for future features (e.g. local trajectory smoothing or safety interlocks) without a redesign.
- Memory and peripheral count: 2 MB of dual-bank Flash and 1 MB of RAM comfortably house the firmware, motion-control lookup tables, and communication buffers, while the device’s multiple hardware SPI, UART, and Timer peripherals allow every joint’s step generation and encoder polling to be assigned dedicated hardware resources rather than being time-multiplexed in software.
- Package and footprint: The LQFP-100 package was chosen over larger BGA H7 variants specifically for hand-solder and low-cost PCBA compatibility during the prototype-to-volume transition described in Chapter 7, avoiding the need for X-ray inspection or specialized reflow profiles associated with BGA assembly.

## 4.2 Core Component Architecture

Beyond the MCU itself, the logic and control domains of the board are built around highperformance processing and precise absolute feedback, summarized below.

### Absolute Position Encoders: AS5047P

Each of the six axes is fitted with an AS5047P magnetic absolute position sensor for closed-loop feedback, communicating with the STM32H743VIT6 over a dedicated high-speed SPI bus rather than relying solely on open-loop step counting or end-of-travel limit switches. This has direct layout consequences for the PCB:

- Bus topology: Each AS5047P is wired to a shared SPI clock and data pair with an individual chip-select (CS) line per axis, allowing the MCU to address each of the six encoders independently on a single physical bus while keeping the harness wire count low.
- Signal integrity: Because the AS5047P’s SPI link operates in the electrically noisy environment created by nearby stepper motor switching, strict signal integrity practices — impedance-controlled routing, ground-plane referencing, and physical separation from motor phase traces — are required to ensure position data is not corrupted in transit; see Section 4.4 for the specific routing techniques used.
- Closed-loop benefit: Because absolute encoders report true joint position rather than accumulated step count, the system inherently self-corrects for any missed microsteps on the open-loop NEMA 17/23 joints, which is central to meeting the sub-millimeter repeatability target validated in Chapter 2 without paying for closed-loop steppers on every axis.

### Motor Drivers: Hybrid On-board and External Topology

The board supports a hybrid driver topology: onboard TMC2209 drivers provide localized, compact control for the smaller NEMA 17 joints, while dedicated opto-isolated headers break out step/direction/enable signals for external industrial drivers such as the CL57T used on the higher-torque NEMA 23/24 joints. The opto-isolation on the external headers galvanically separates the MCU’s 3.3 V logic domain from the higher-current, highervoltage external driver stage, protecting the STM32H743VIT6 from transients generated by the larger closed-loop motors.

### Power Delivery and Protection

The board’s Power Delivery Network (PDN) steps down and regulates supply voltage in stages: a 12 V main input feeds a 5 V buck converter for intermediate rails and peripheral power, which in turn feeds 3.3 V regulation for the MCU and digital logic. USB-sourced power is combined with the main supply using diode-OR’ing built around the 1N5819HW-7-F Schottky diode, chosen for its low forward-voltage drop and fast switching to provide reverse-current protection without materially reducing the available USB power budget.

### Timing: External HSE Crystal

An external 8 MHz quartz crystal oscillator (HSE, High-Speed External) drives the STM32H743VIT6’s Phase-Locked Loop (PLL), which multiplies this reference up to the clock rates needed for accurate USB Full-Speed communication (48 MHz) and precise step-pulse generation. Matched load capacitors on the crystal legs are selected to the manufacturer’s specified load capacitance to ensure reliable startup and frequency accuracy; see Section 4.4 for the associated layout precautions.

## 4.3 The PCB Stackup

The board is designed in Altium Designer using a standard 4-layer stackup. Driving heavy inductive loads (the NEMA stepper motors) mere millimeters away from sensitive 3.3 V digital logic and high-speed SPI lines requires strict physical separation that a 2-layer board cannot provide, so the 4-layer stackup is used for the current design rather than treated as a future-only upgrade path. The stackup delivers three concrete benefits:

- Power Delivery Network (PDN) optimization: Dedicated internal power and ground planes provide a low-impedance return path for the high-current 12 V transients generated by the stepper motors, preventing ground bounce that could otherwise destabilize or crash the STM32H743VIT6.
- Signal Integrity (SI): Ground planes placed directly adjacent to signal layers allow tightly coupled return currents, containing electromagnetic interference (EMI) and preventing the fast di/dt switching noise of the motor drivers from coupling into the AS5047P SPI lines.
- Thermal dissipation: The internal copper planes act as distributed heatsinks, drawing thermal energy away from the onboard TMC2209 drivers and the power regulator stages.

Figure 4.3 shows the routed copper on all four layers of the board, extracted directly from the Altium Designer layout.

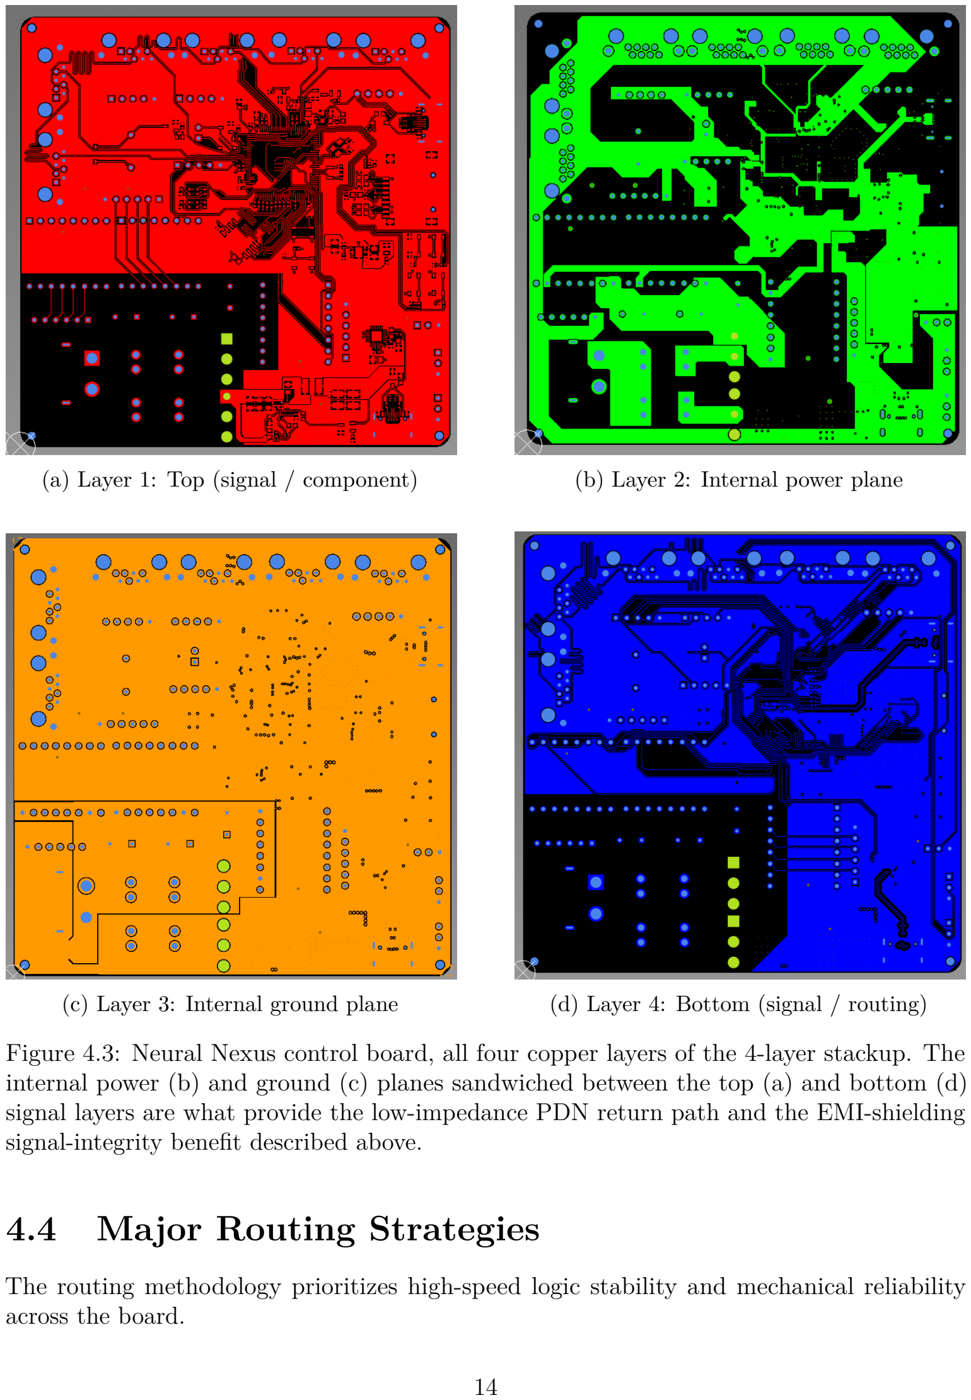
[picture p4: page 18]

(a) Layer 1: Top (signal / component) | (b) Layer 2: Internal power plane
(c) Layer 3: Internal ground plane | (d) Layer 4: Bottom (signal / routing)

Figure 4.3: Neural Nexus control board, all four copper layers of the 4-layer stackup. The internal power (b) and ground (c) planes sandwiched between the top (a) and bottom (d) signal layers are what provide the low-impedance PDN return path and the EMI-shielding signal-integrity benefit described above.

## 4.4 Major Routing Strategies

The routing methodology prioritizes high-speed logic stability and mechanical reliability across the board.

- Impedance-controlled routing: High-speed communication lines — specifically the USB differential pair (D+/D–) and the SPI buses to each AS5047P encoder — are routed as controlled-impedance traces referencing the continuous internal ground plane, preventing signal reflection that could corrupt encoder reads or USB enumeration.
- Optimized polygon pours: Ground planes and copper pours follow strict clearance design rules to avoid manufacturing defects such as localized short-circuits that could inadvertently ground an active signal (an early revision surfaced exactly this risk around the SPI Flash and a motor direction pin, which the current clearance rules are designed to prevent from recurring).
- Parasitic capacitance mitigation: Traces connecting the 8 MHz HSE crystal to the MCU’s oscillator pins are routed as short and symmetrically as possible, avoiding vias and adjacent high-speed switching lines. This minimizes stray capacitance (Cstray), ensuring the crystal starts up reliably and the PLL remains locked at exactly 48 MHz for USB enumeration.
- Mechanical integration: The board layout incorporates specific mechanical mounting holes, a custom board outline, and cutouts (visible around the connector edges in Figures 4.1 and 4.2) to physically mate the PCB securely to the robotic arm chassis.

## 4.5 Additional Layout Considerations

- Power and signal separation: High-current motor driver traces (TMC2209 / CL57T supply and phase lines) are routed on wider copper pours and physically separated from low-voltage logic, UART, and SPI signal traces to minimize EMI coupling into the control and encoder-feedback lines. This is visible in Figure 4.2, where the highlighted high-current motor driver pours are kept clear of the logic and SPI routing above them.
- Grounding strategy: A unified ground plane pour is used beneath the MCU, logic, and communication sections (including the SPI encoder bus) to reduce ground-loop noise, with star-point grounding back to the main power entry for the motor driver stages.
- Connector selection: Locking, keyed RJ-style connectors are specified for the motor, limit-switch, and per-axis SPI encoder harnesses (top edge of Figure 4.1) to prevent field mis-wiring during assembly or maintenance — an important reliability consideration for a product intended for continuous industrial duty.
- Design for Automated Assembly (DFM/DFA): Component footprints, spacing, and fiducial placement follow standard pick-and-place tolerances so that the board can transition directly to a Turnkey PCBA process at volume without redesign, reducing manual labor costs during scaling (see Chapter 7).

## 4.6 Full Schematic Capture

[This section is reserved for the full net-level schematic capture (Altium Designer schematic print, all sheets), to be merged in as a standalone PDF insert. The 3D layout renders in Sections 4.2–4.5 above reflect the current board design; the schematic pages that follow provide the corresponding net-level detail.]

## 4.7 Per-Axis Encoder Daughterboards (Motor-Specific Variants)

In addition to the main control board (Figures 4.1–4.3), each joint carries a small encoder daughterboard mounted directly on its motor, hosting that axis’s AS5047P and its local signal conditioning close to the magnet target for the shortest possible sense-to-ADC path. Since the six joints use three different NEMA frame sizes (Chapter 6), the daughterboard outline and mounting-hole pattern are adapted per motor size while the sensor circuit itself — AS5047P, decoupling, protection diode, and the JST/RJ harness pair back to the main board — stays identical across variants for BOM commonality. Four board variants are currently in use.

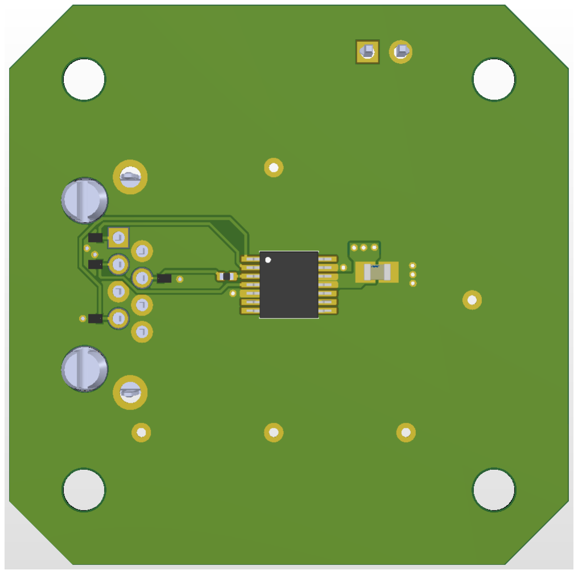
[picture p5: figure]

(a) Component side: AS5047P encoder IC and local decoupling/pull-up passives

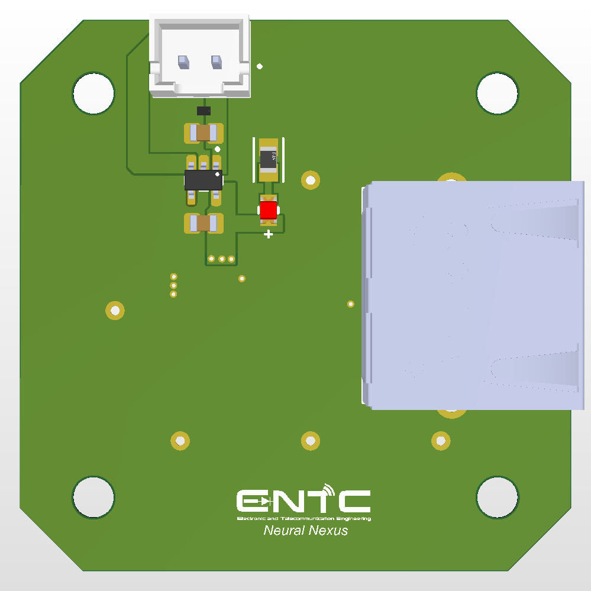
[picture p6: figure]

(b) Connector side: JST power/data connector, protection diode, and RJ-style SPI harness header back to the main control board

Figure 4.4: Standard NEMA17 variant, used on the open-loop NEMA17 joints. The octagonal outline and four mounting holes allow it to be secured directly to the rear of the motor housing, keeping the AS5047P concentric with the shaft-mounted diametric magnet.

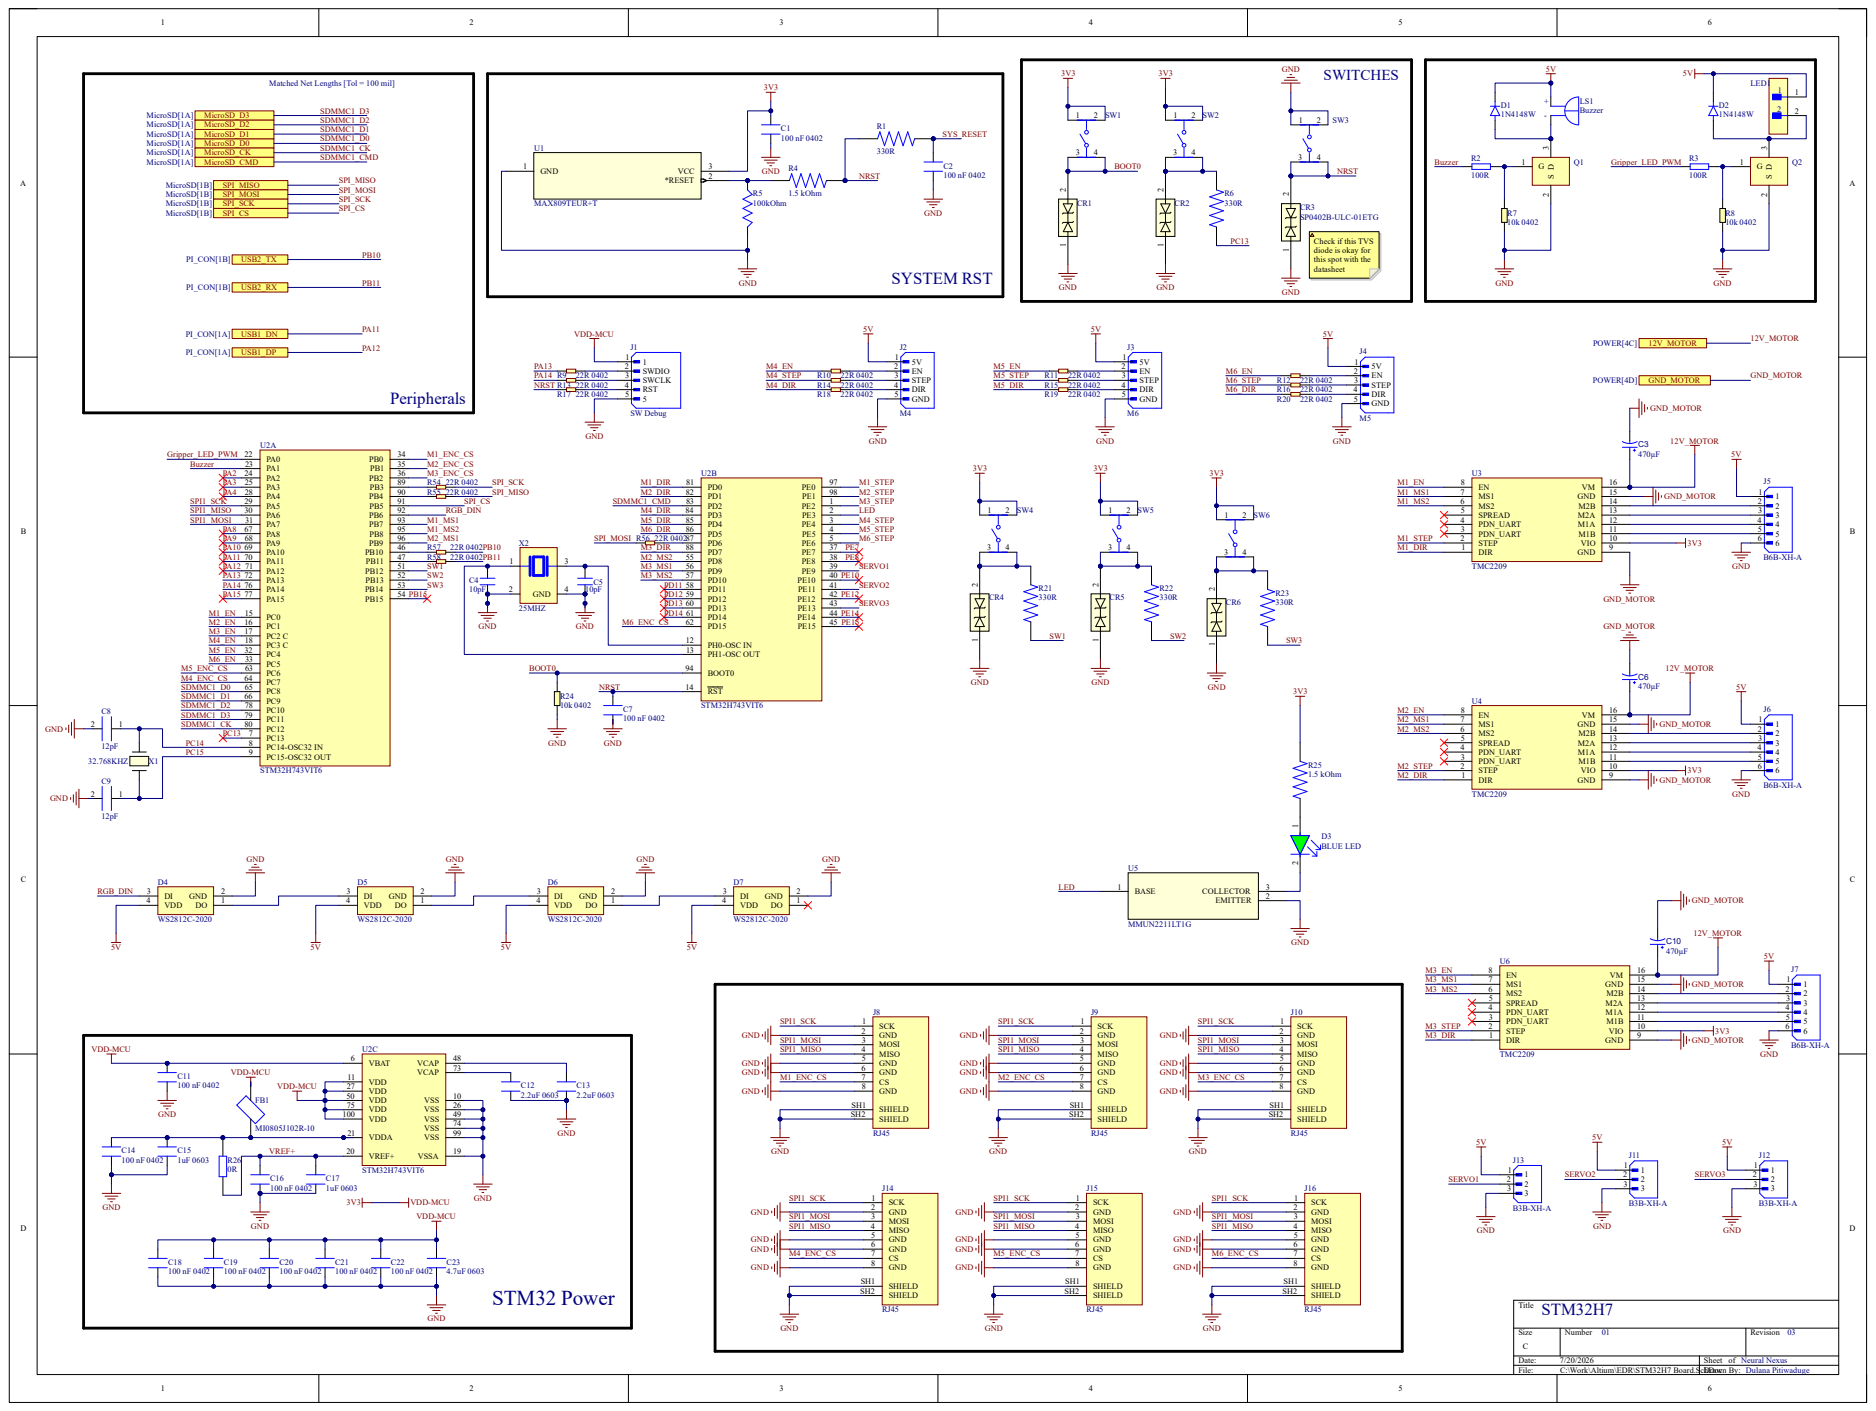
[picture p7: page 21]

Matched Net Lengths [Tol = 100 mil]

Check if this TVS
diode is okay for
this spot with the
datasheet

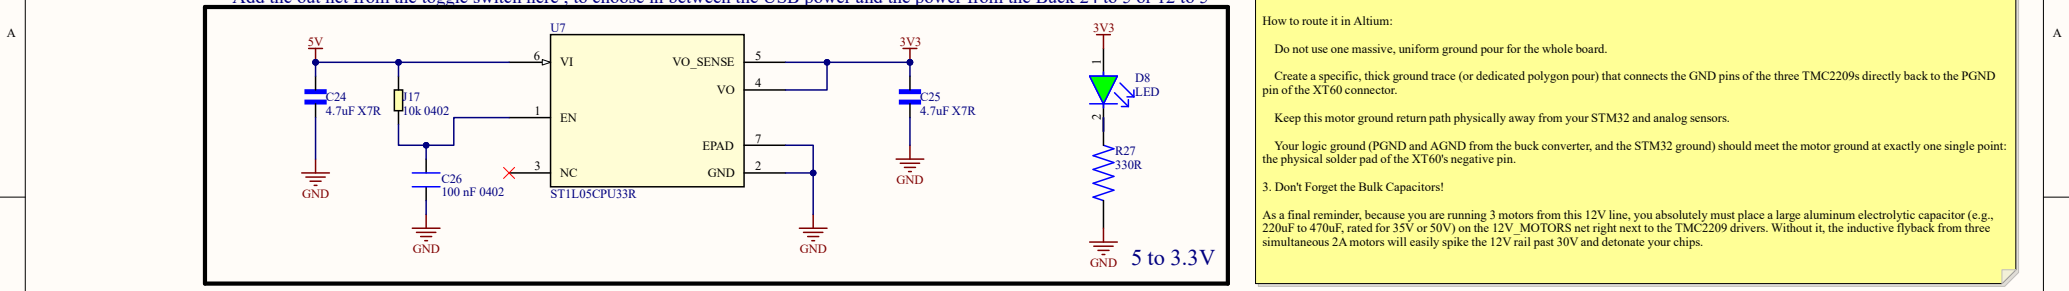
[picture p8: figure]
GND; VO_SENSE; EPAD; ST1L05CPU33R; D8 LED; How to route it in Altium:; pin of the XT60 connector.; 3. Don't Forget the Bulk Capacitors!
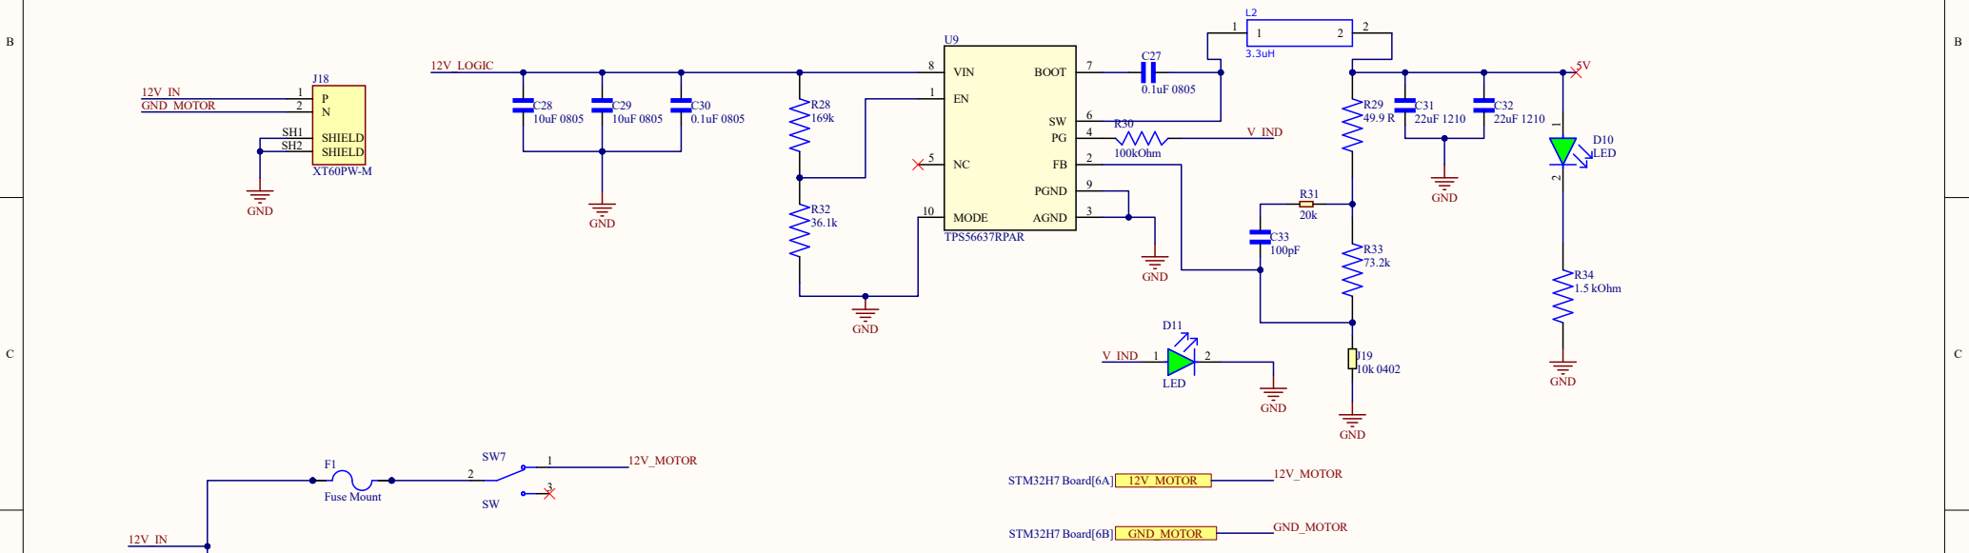
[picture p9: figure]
AGND; BOOT; 7 VIN 8; PGND; MODE 10; TPS56637RPAR; SHIELD SH1 SHIELD SH2; GND; 12V_LOGIC; GND_MOTOR; 100kOhm; LED; V_IND; 12V_MOTOR; STM32H7 Board[6A] 12V_MOTOR; STM32H7 Board[6B] GND_MOTOR; D10 LED; R34 1.5 kOhm; Fuse Mount

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
Title

Size | Number | Revision
B
Date: | 7/20/2026 | Sheet of
File: | C:\Work\Altium\EDR\POWER.SchDoc | Drawn By:

### POWER

Add the out net from the toggle switch here , to choose in between the USB power and the power from the Buck 24 to 5 or 12 to 5

12V_LOGIC
2

1

3

SW8

SW

F2

Fuse Mount

Neural Nexus
Dulana Pitiwaduge

02 04

Splitting the 12V line is only half the battle; you must also manage the ground return paths.

When those three motors pull 6A, that 6A has to flow back to the battery through the ground plane. If that 6A flows underneath or through the ground copper near your STM32 or your TPS56637 feedback resistors, it will raise the local ground voltage, causing your microcontroller to read false button presses, corrupt SPI data, or trigger a brown-out reset.

Do not use one massive, uniform ground pour for the whole board.

Create a specific, thick ground trace (or dedicated polygon pour) that connects the GND pins of the three TMC2209s directly back to the PGND

Keep this motor ground return path physically away from your STM32 and analog sensors.

Your logic ground (PGND and AGND from the buck converter, and the STM32 ground) should meet the motor ground at exactly one single point: the physical solder pad of the XT60's negative pin.

As a final reminder, because you are running 3 motors from this 12V line, you absolutely must place a large aluminum electrolytic capacitor (e.g., 220uF to 470uF, rated for 35V or 50V) on the 12V_MOTORS net right next to the TMC2209 drivers. Without it, the inductive flyback from three simultaneous 2A motors will easily spike the 12V rail past 30V and detonate your chips.

# GND 1 2

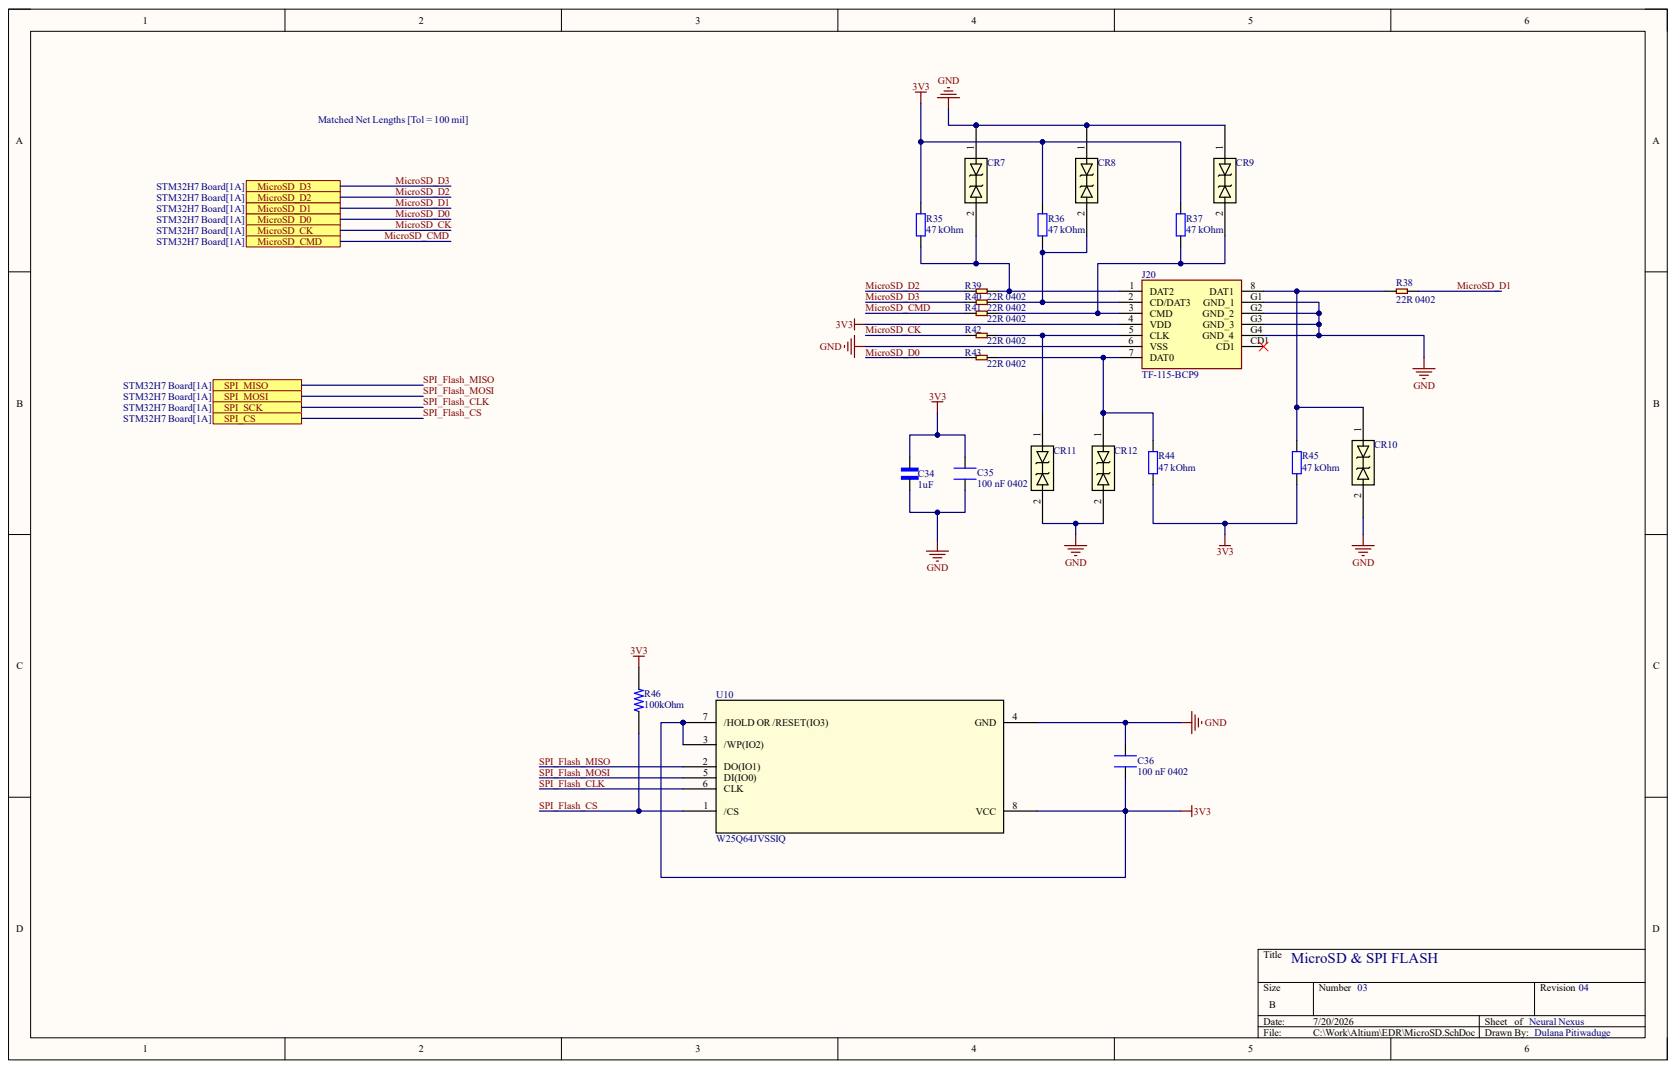
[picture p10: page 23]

Matched Net Lengths [Tol = 100 mil]

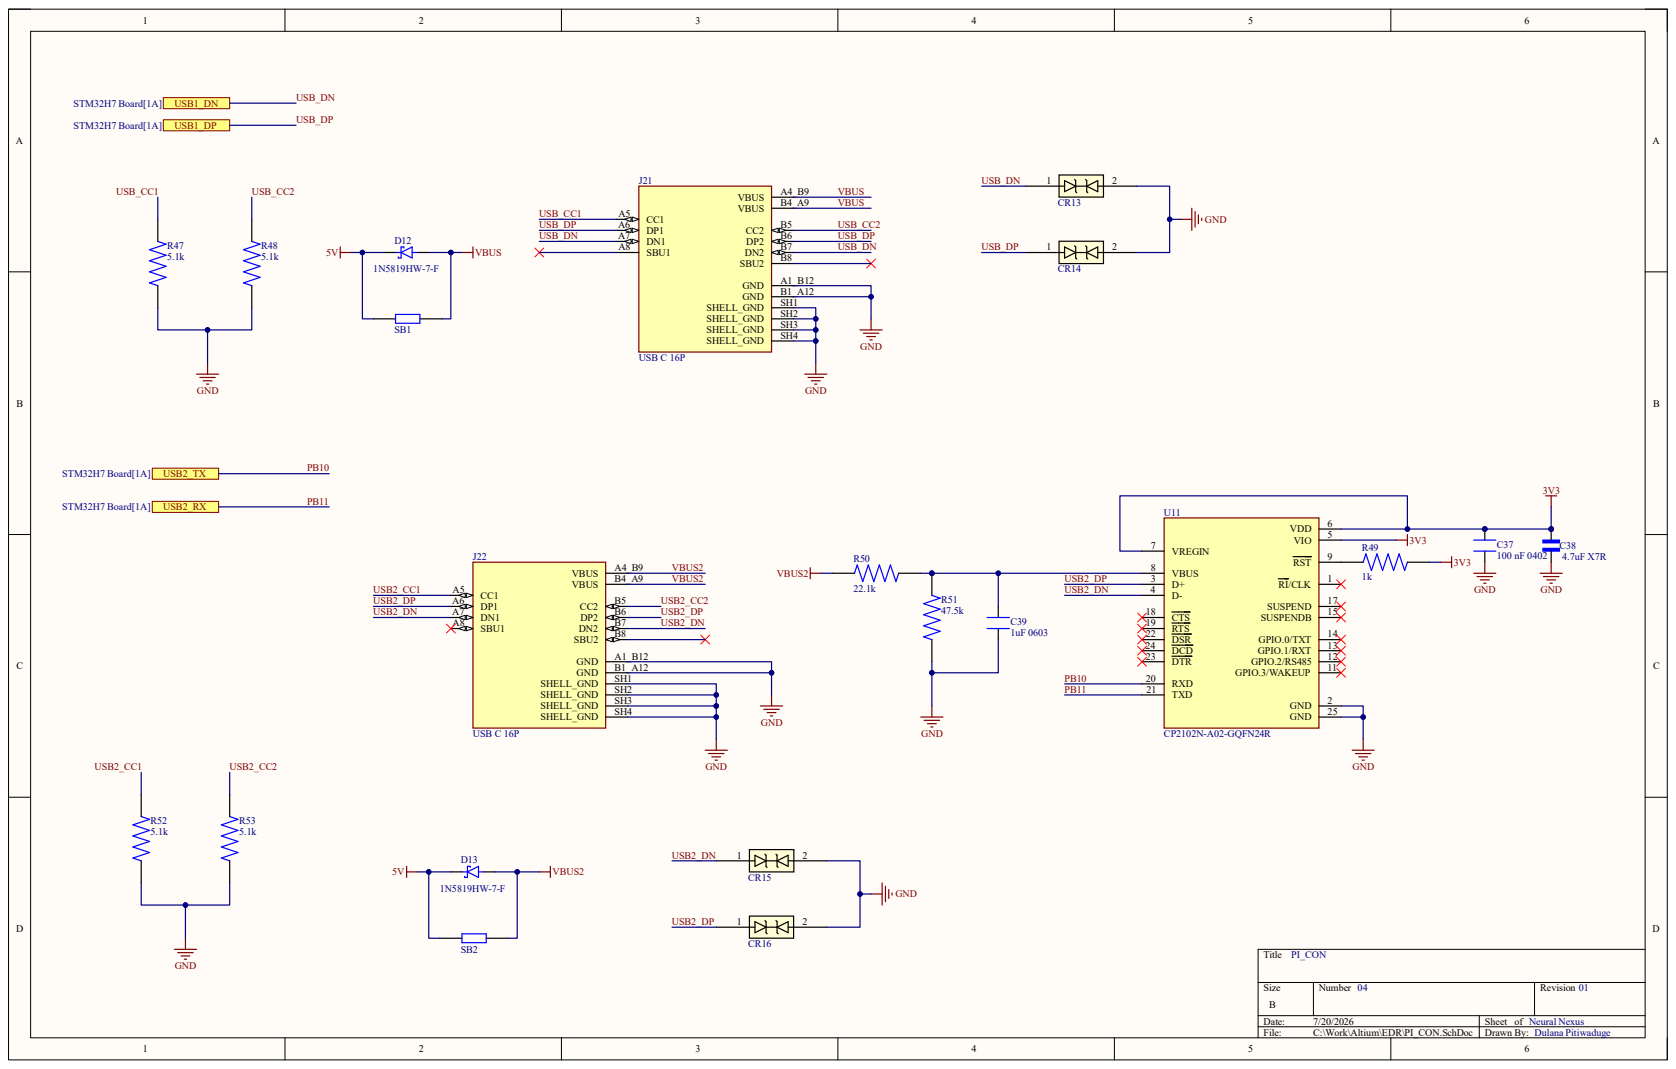
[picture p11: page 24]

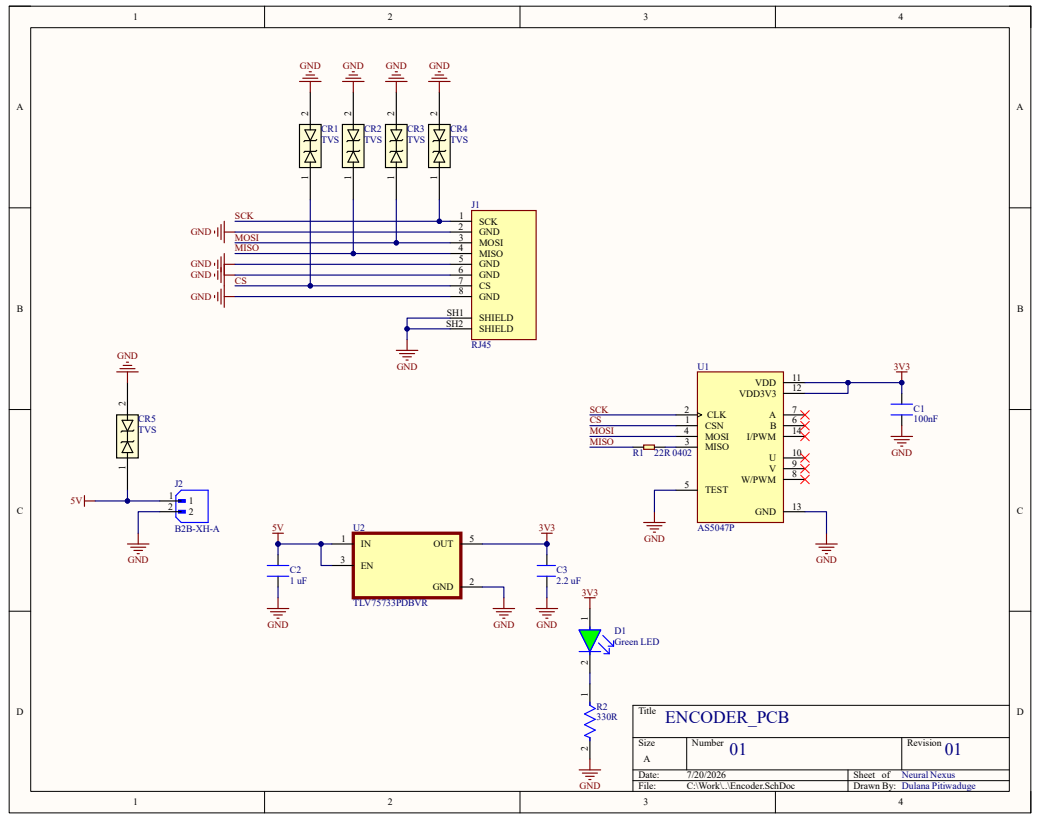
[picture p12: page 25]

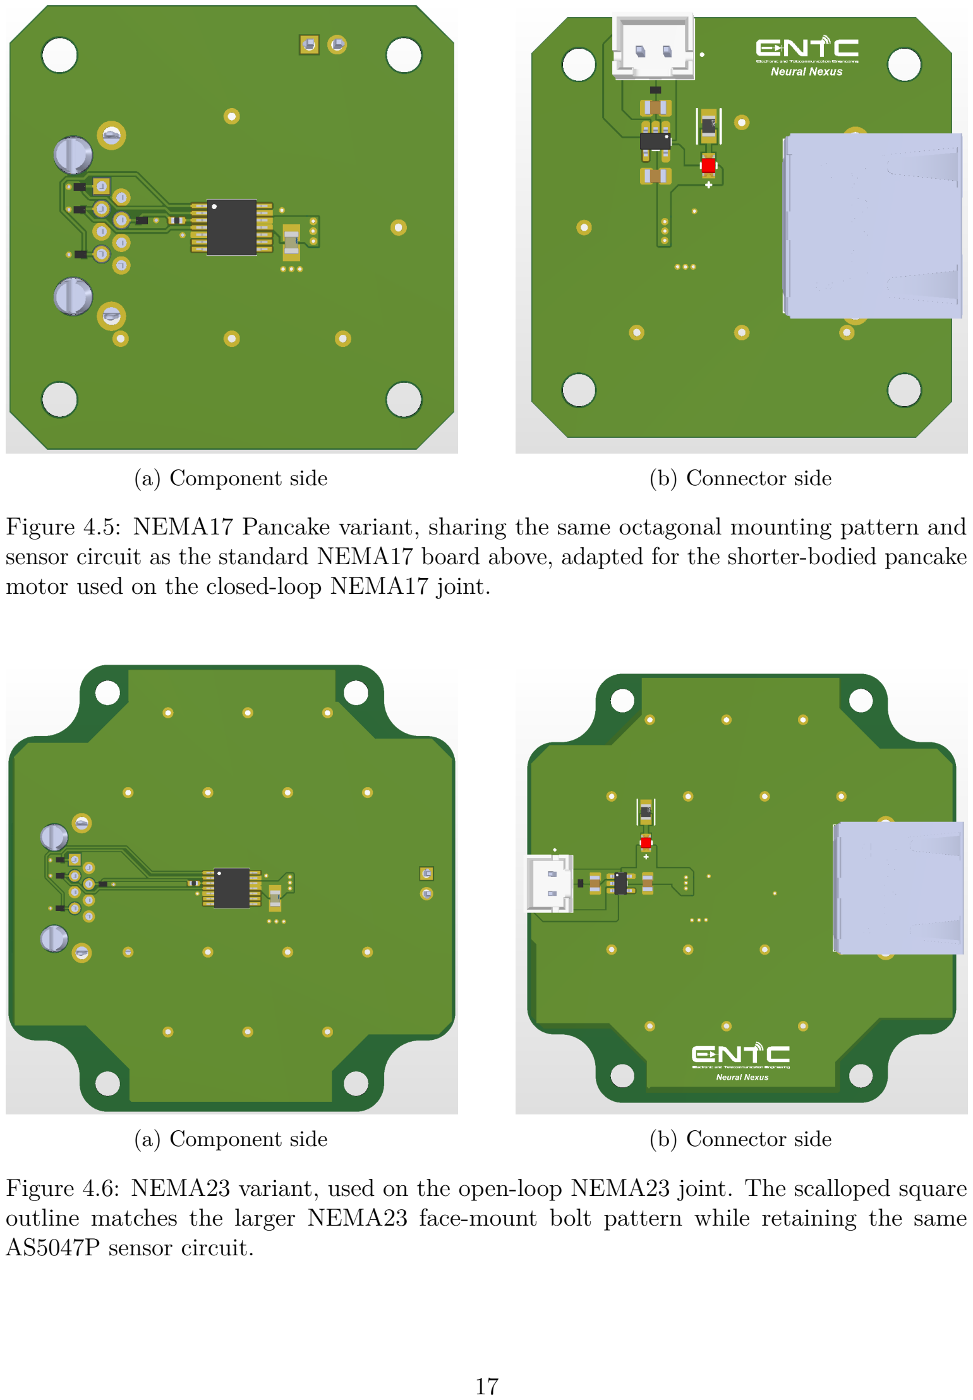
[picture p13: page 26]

(a) Component side | (b) Connector side

Figure 4.5: NEMA17 Pancake variant, sharing the same octagonal mounting pattern and sensor circuit as the standard NEMA17 board above, adapted for the shorter-bodied pancake motor used on the closed-loop NEMA17 joint.

(a) Component side | (b) Connector side

Figure 4.6: NEMA23 variant, used on the open-loop NEMA23 joint. The scalloped square outline matches the larger NEMA23 face-mount bolt pattern while retaining the same AS5047P sensor circuit.

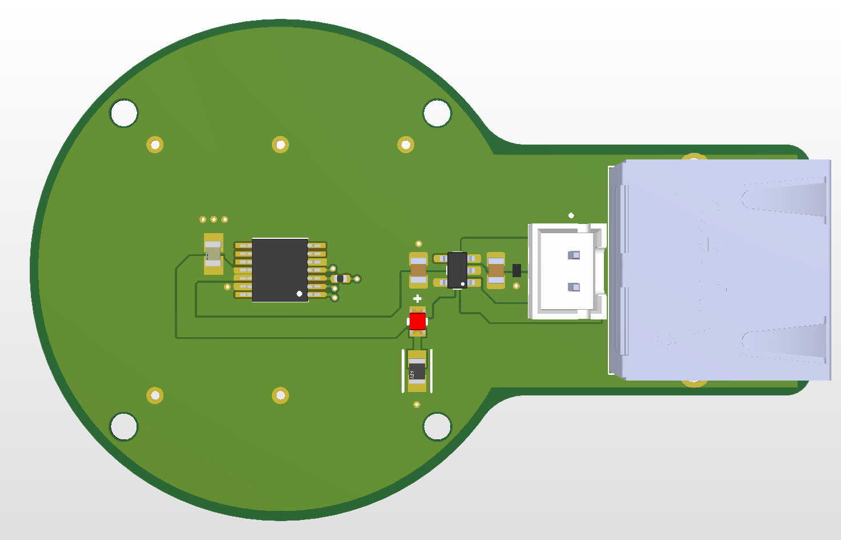
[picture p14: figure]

(a) Component side | (b) Connector side

Figure 4.7: NEMA24 variant, used on the two closed-loop NEMA24 joints. The extended “lollipop” outline places the sensor circuit on a larger circular head to clear the NEMA24 motor’s wider diametric-magnet target, with the same JST/RJ harness pair as the other variants.

Because these daughterboards sit physically close to each motor’s own switching noise, their short JST harnesses back to the main board’s RJ-style encoder headers (Section 4.5) are the first and most exposed leg of the SPI signal path described in Section 4.2, which is why the impedance-controlled routing and physical separation practices in Section 4.4 are applied consistently across all four board variants and the main control board alike.

# Chapter 5

# Product Enclosures and Sketches

## 5.1 Initial CAD Design Iterations

Figure 5.1 shows the early full-assembly CAD models used to block out the arm’s joint envelopes, motor placement, and belt/pulley transmissions before any physical fabrication began.

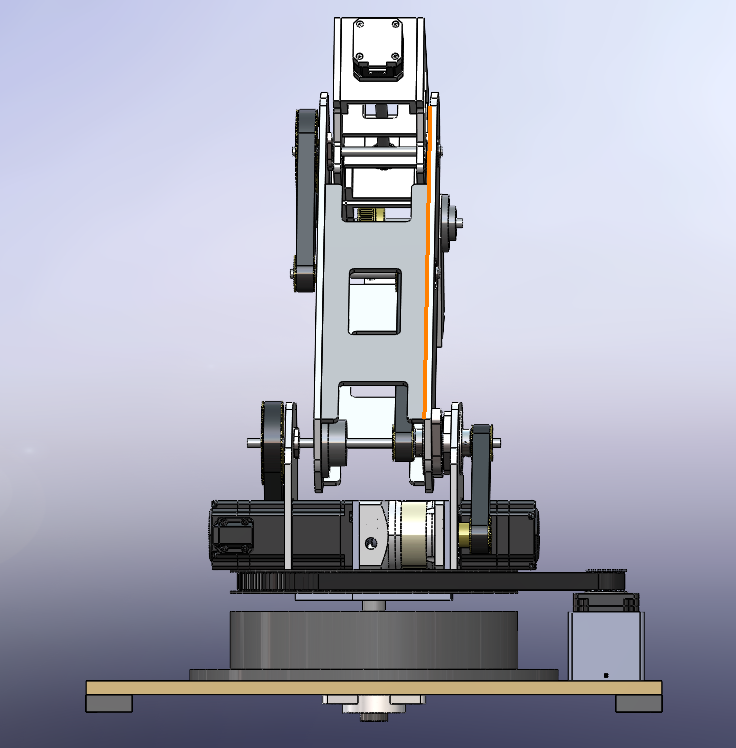
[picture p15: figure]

(a) Front elevation with the critical drive-belt path highlighted (orange), showing the shoulder pulley train and internal linkage detail
(b) Side elevation, full arm in a raised working pose
(c) Side elevation, matte render of the finalized link geometry

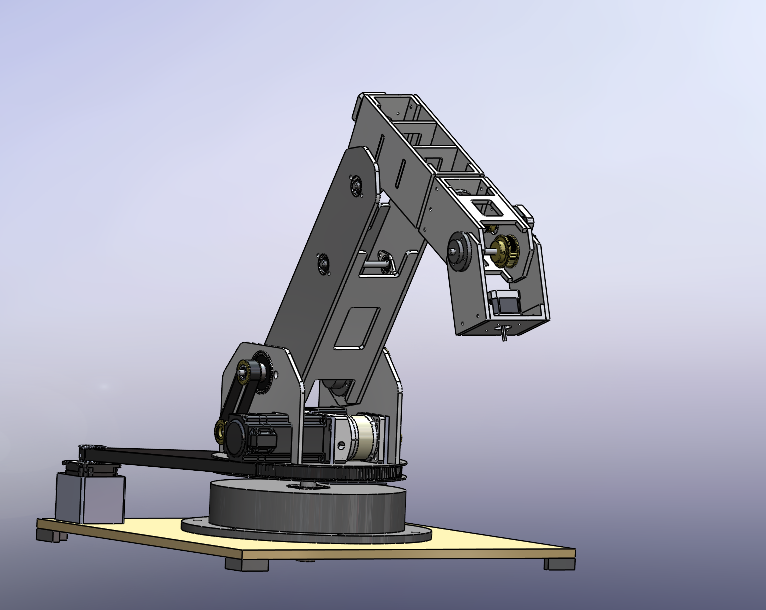
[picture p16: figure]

(d) Isometric view, full assembly on the mounting baseplate

Figure 5.1: Neural Nexus initial full-assembly CAD design iterations, showing the belt-andpulley shoulder/elbow transmission and NEMA motor placement arrived at before fabrication.

Figures 5.2 and 5.3 focus in on the base/shoulder motor cluster, where the majority of the mechanical design iteration took place.

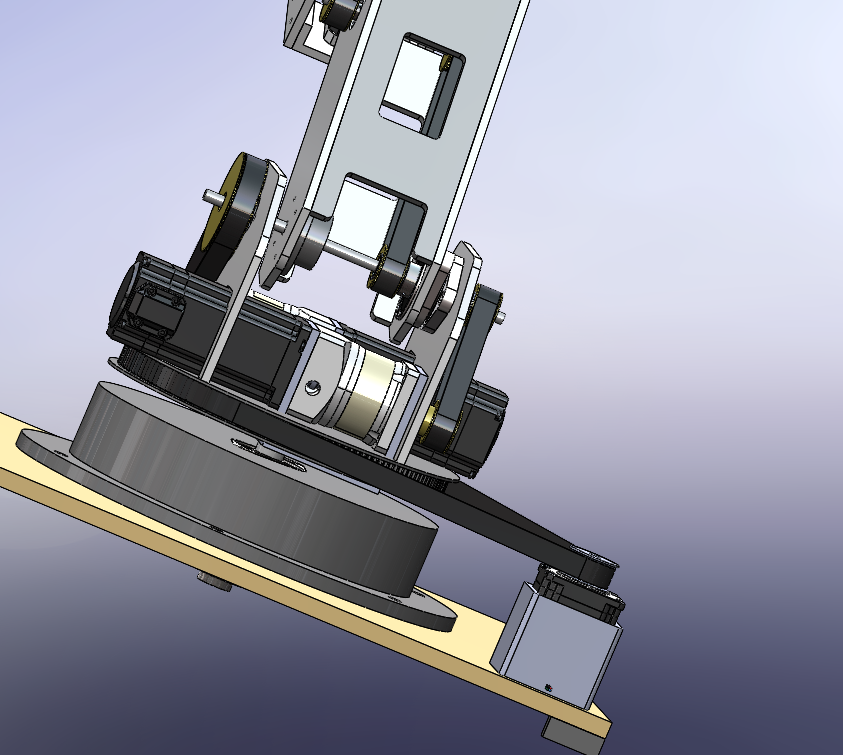
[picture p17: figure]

Figure 5.2: Close-up of the base and shoulder motor cluster, showing the paired NEMA motors either side of the shoulder pulley and the large slewing ring at the base rotation joint.

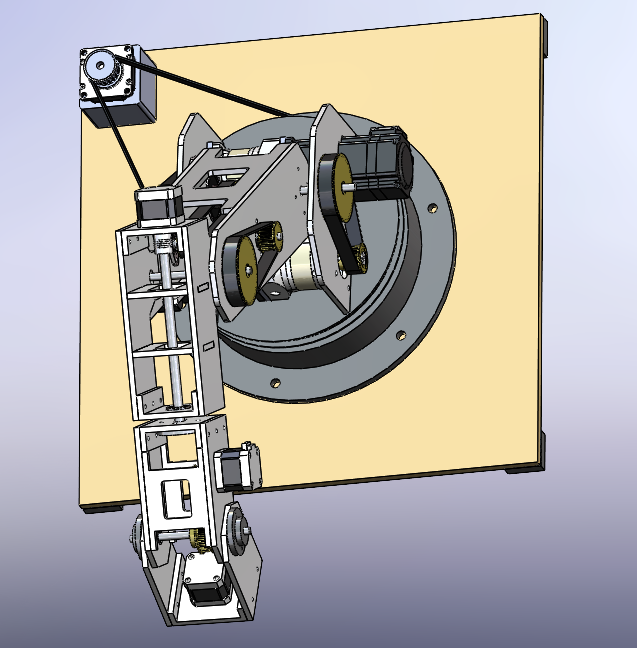
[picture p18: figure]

Figure 5.3: Rear-angled view of the base rotation assembly, mounted against its plywood test fixture panel, showing the belt routing between the base-mounted motor and the shoulder joint.

## 5.2 Finalized CAD Design

Following the initial iterations above, the design was finalized with three key mechanical revisions: a redesigned base gear and mounting plate, finalized motor placement fully secured with screws throughout (rather than the loosely positioned motors of the earlier iterations), and additional structural integrity supports between the shoulder link plates. Figure 5.4 shows the finalized assembly from four viewpoints.

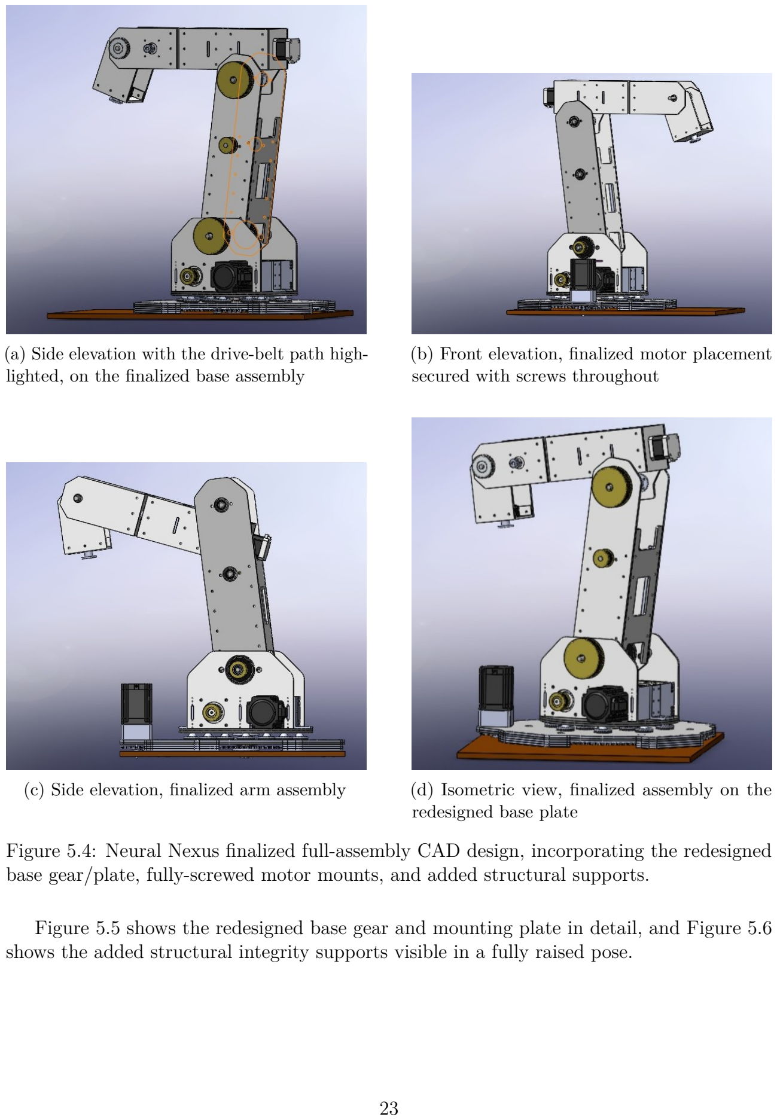
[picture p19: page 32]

(a) Side elevation with the drive-belt path highlighted, on the finalized base assembly
(b) Front elevation, finalized motor placement secured with screws throughout
(c) Side elevation, finalized arm assembly | (d) Isometric view, finalized assembly on the redesigned base plate

Figure 5.4: Neural Nexus finalized full-assembly CAD design, incorporating the redesigned base gear/plate, fully-screwed motor mounts, and added structural supports.

Figure 5.5 shows the redesigned base gear and mounting plate in detail, and Figure 5.6 shows the added structural integrity supports visible in a fully raised pose.

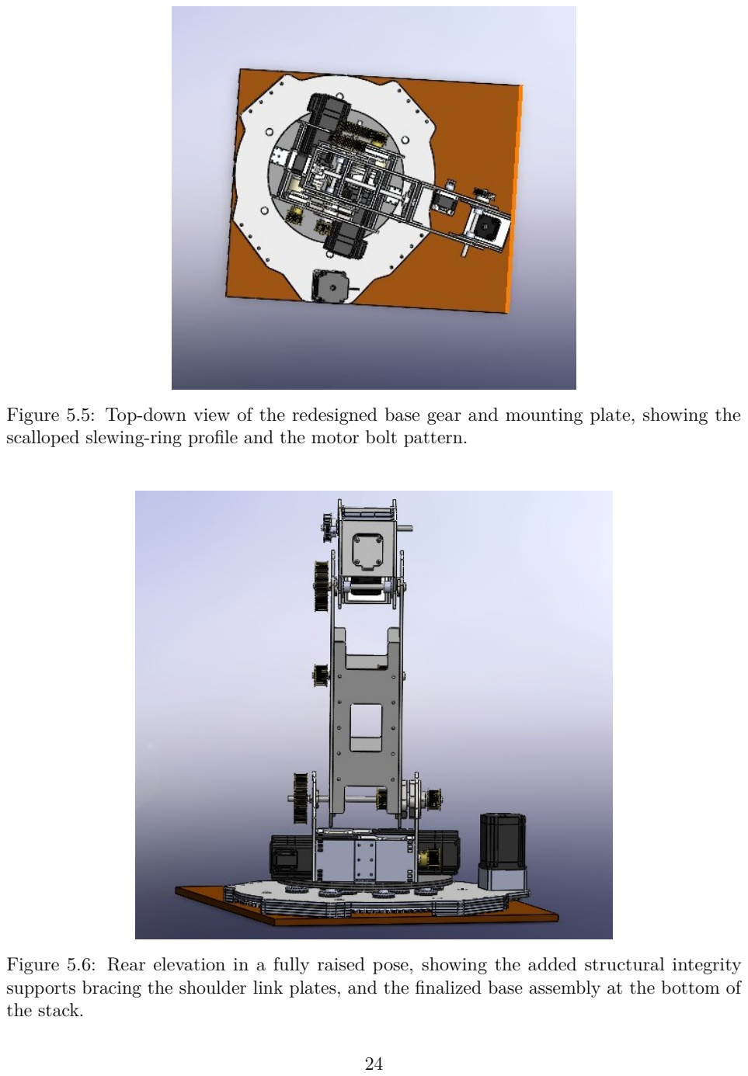
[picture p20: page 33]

Figure 5.5: Top-down view of the redesigned base gear and mounting plate, showing the scalloped slewing-ring profile and the motor bolt pattern.

Figure 5.6: Rear elevation in a fully raised pose, showing the added structural integrity supports bracing the shoulder link plates, and the finalized base assembly at the bottom of the stack.

## 5.3 Electronics Enclosure (Control Box)

In addition to the arm structure itself, the custom control board (Chapter 4) is housed in its own finalized vented enclosure, shown in Figure 5.7. The enclosure is laser-cut/engraved with the Neural Nexus branding on the perforated top panel, which doubles as the primary ventilation path directly above the board.

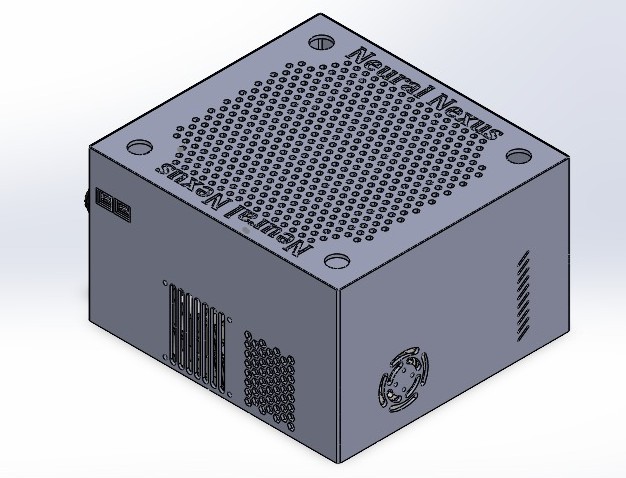
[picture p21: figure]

Figure 5.7: Isometric view of the finalized electronics enclosure, showing the perforated top vent panel with the Neural Nexus branding, side ventilation slots, a cable-gland cutout on the left face, and the axial fan mount on the front-right face.

Figure 5.8 shows the flattened side-panel layout, including the cable-gland glands for the motor/encoder harnesses leaving the box, the status-indicator cutouts above them, and the combined slot-and-hex ventilation pattern used to balance airflow with EMI shielding on the panel nearest the TMC2209/CL57T driver stage.

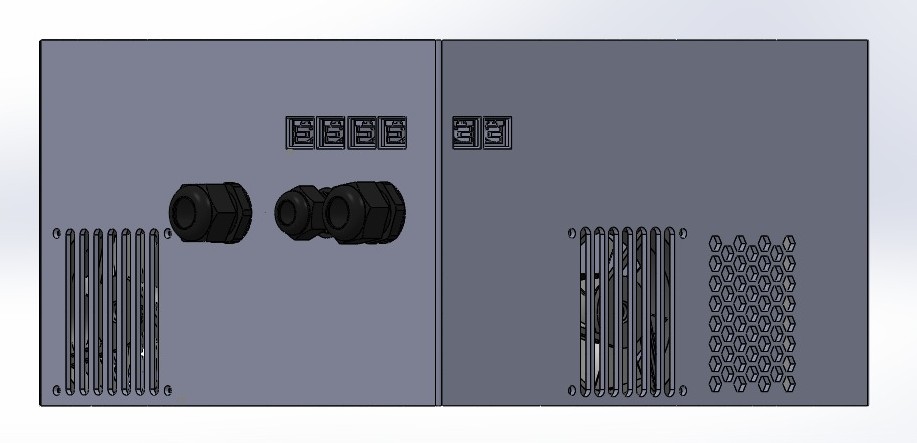
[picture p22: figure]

Figure 5.8: Flattened view of the two side panels: cable-gland harness exits and status-indicator cutouts (left panel), and the slot-and-hex ventilation pattern over the driver stage (right panel).

## 5.4 Design Evolution Notes

The enclosure design progressed through three stages: (1) low-fidelity conceptual hand sketches used to block out joint envelopes and cable routing paths, (2) intermediate CAD models such as those in Figures 5.1–5.3, used to validate motor mounting, bearing seats, and wire-management channels against the aluminum structural frame, and (3) the finalized CAD design in Figures 5.4–5.6, incorporating the redesigned base gear/plate, fully-screwed motor mounts, and structural integrity supports, optimized for 3D-printability at the prototype stage and for future rapid injection molding at volume production. Draft angles, wall thicknesses, and parting lines in the finalized CAD models were selected specifically to ease the eventual transition to injection-molded tooling described in Chapter 7.

# Chapter 6

# Final Product Details and Operational Value

The Neural Nexus robotic arm is a desktop-sized automation unit capable of complex pick-and-place, assembly, and research tasks.

## 6.1 Final Product Specifications

- Degrees of Freedom: 6 DOF (Enables full 3D workspace with arbitrary end-effector orientation, maximizing factory floor utility and spatial efficiency).
- Maximum Reach (Arm Span): 800mm (Optimized specifically to span standard industrial conveyor belts and sorting tables).
- Payload Capacity: 2kg (Ideal for SME machine tending, electronics assembly, and lightweight FMCG packaging).
- Actuation System: 2 × NEMA 24 (Closed Loop), 1 × NEMA 23 (Open Loop), 3 × NEMA 17 (1 Closed, 2 Open). Torque-matched per joint to reduce moving mass and energy consumption.
- Master Control Unit (MCU): Custom PCB built around an STM32H743VIT6 (Arm Cortex-M7, up to 480 MHz, 2 MB Flash, 1 MB RAM, LQFP-100), generating step/direction pulses for all six axes on dedicated hardware timers and closing the position loop via SPI-connected AS5047P magnetic absolute encoders on each joint.
- Position Feedback: Six AS5047P magnetic absolute encoders (one per axis), polled over a shared SPI bus with individual per-axis chip-select lines, providing true joint-position feedback independent of step count.
- Power Consumption & Requirements: Mains powered (230 V AC). As a highuptime industrial asset, the system is tethered to ensure 24/7 continuous operational capability without battery degradation concerns. Table 6.1 gives engineering estimates based on manufacturer motor and driver datasheets; these are to be confirmed against bench measurements on the final assembled unit.

- Modular Upgradability: The tool-head is designed to be hot-swappable, allowing businesses to adapt the robot from a vacuum gripper to a mechanical claw with minimal downtime, extending the Total Cost of Ownership (TCO) lifespan.
Operating State | Estimated Draw Notes
Idle / holding torque | ∼80–120 W All six drivers energized, no motion
Typical operation (single- axis moves) | ∼200–300 W Sequential joint moves, light payload
Peak (coordinated multi- axis move, full payload) | ∼500–650 W All motors near rated current simultaneously

Table 6.1: Estimated power draw by operating state (to be validated by bench measurement)

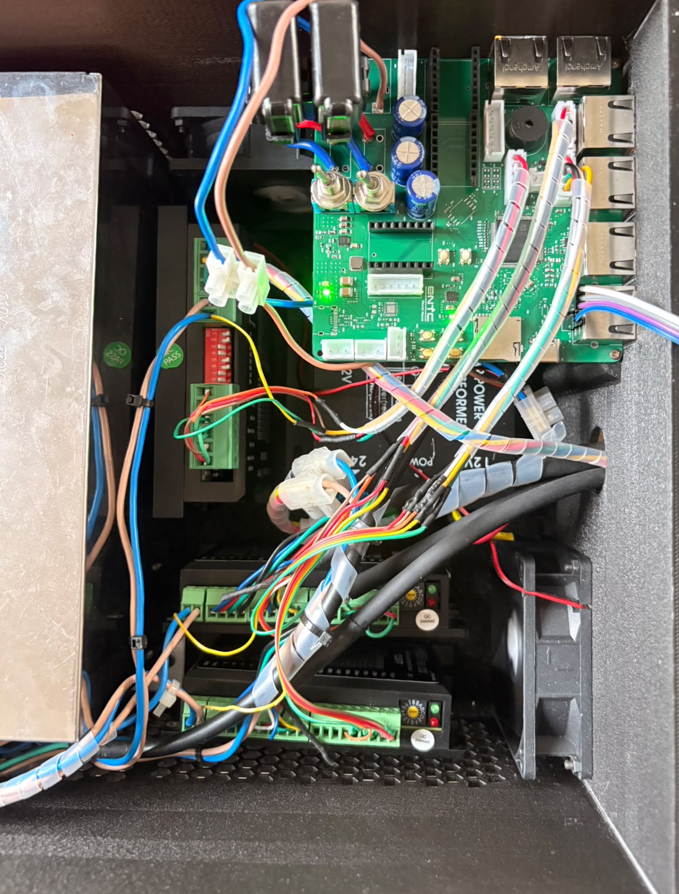
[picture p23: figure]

Figure 6.1: Interior of the assembled electronics enclosure (Chapter 5), showing the custom STM32H743VIT6 control board mounted alongside the CL57T driver modules, terminal blocks, cooling fan, and the harness routing described in Chapter 4.

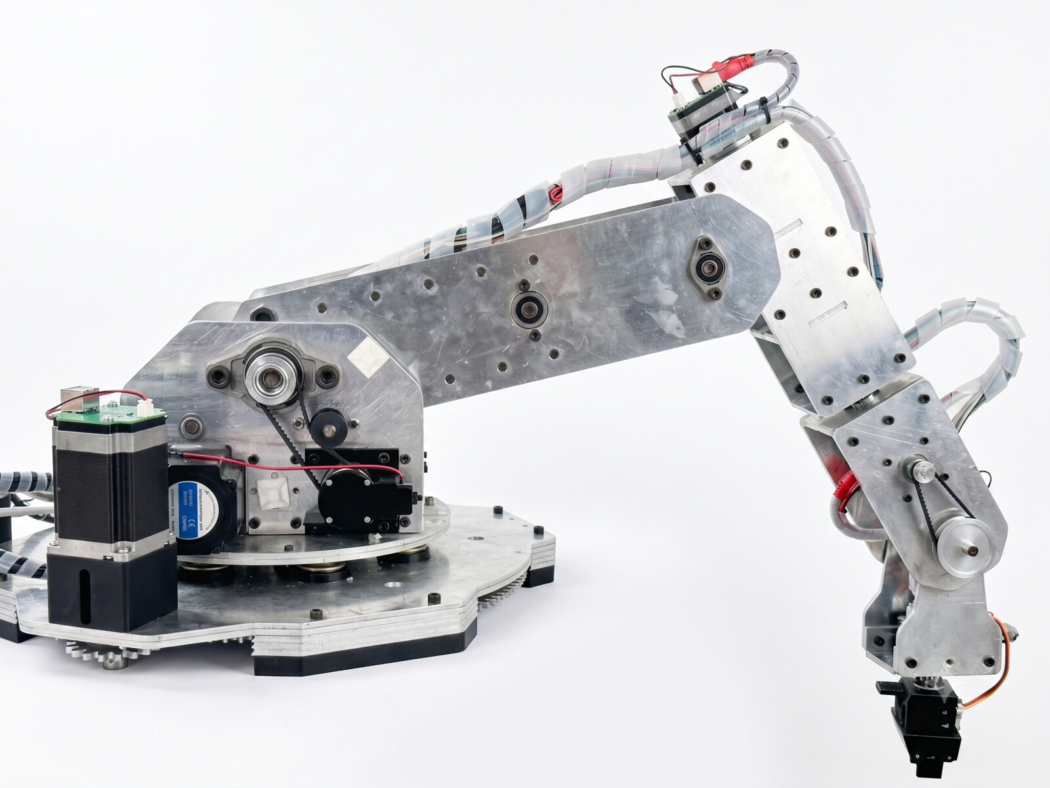
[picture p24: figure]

# Chapter 7

# Manufacturing Considerations (Volume Production)

Transitioning Neural Nexus from a functioning prototype to volume manufacturing requires strict supply chain management and fabrication standardization to protect our profit margins against local inflation and logistical shocks.

- Material Sourcing & BOM Resilience: Bulk sourcing of standardized aluminum sheets (8

′ ×4

′ ×4mm) is critical to keeping chassis costs low. By utilizing raw materials widely available in Sri Lanka, we insulate our Bill of Materials (BOM) from localized price fluctuations and import bans.

- Automated Fabrication: Moving from manual prototyping to automated CNC routing and laser cutting for the mechanical linkages will ensure repeatable, industrial-grade tolerances while drastically reducing labor hours (and thus OPEX) per unit.
- Electronics Assembly: Transitioning to a Turnkey PCBA (Printed Circuit Board Assembly) manufacturer for volume batches rather than in-house soldering. This reduces defect rates and accelerates production timelines.
- Quality Assurance (QA) & Calibration: Implementing a rigorous end-of-line calibration rig using our MATLAB Digital Twin to verify the IK accuracy and payload capacity of every unit before shipping. This step is vital to reducing costly warranty returns and maintaining brand reputation.
- Supplier Redundancy: Qualifying at least two suppliers for each critical component category (motors, drivers, aluminum stock) to avoid single-source risk as production scales.

# Chapter 8

# Costing, Pricing Strategy, and Customer ROI

## 8.1 Volume Production Costing (COGS)

Based on current batch sourcing and local material procurement, the absolute Cost of Goods Sold (COGS) to manufacture a single prototype unit — taken as the actual total project value tracked in Chapter 10 (pooled contributions, donations, and the member-covered deficit) — stands at 568,982.27 LKR. As we scale to volume production, economies of scale (e.g., bulk CNC machining and PCBA runs) are expected to drive this material cost down further.

## 8.2 Determination of Selling Price & Business Justification

The suggested retail price for the base Neural Nexus arm is strategically set at 1,500,000 LKR.
The Financial Justification: In hardware manufacturing, long-term financial sustainability requires a robust operating buffer. By pricing the arm using an industry-standard ∼ 2.6× multiplier of our component cost, we secure the necessary capital to cover Customer Acquisition Costs (CAC), continuous R&D, marketing overhead, and maintaining a reliable 24/7 after-sales support network.
At this price point, Neural Nexus generates over 931,017.73 LKR in gross profit per unit (a highly attractive 62.07% Gross Margin). This robust margin allows us to rapidly scale our software engineering team to develop advanced SaaS features while maintaining a zero-downtime local repair network—a massive competitive advantage over foreign suppliers.

## 8.3 Total Cost of Ownership (TCO) and Customer ROI

For the SME consumer, the business case is undeniably strong. The baseline for comparable imported models is often over 2,000,000 LKR, excluding shipping and the local import levy stack (18% VAT, 7.5% PAL, and 2.5% SSCL, detailed in Chapter 1) that would apply on top if imported directly. By pricing at 1.5M LKR and manufacturing locally, we lower the capital barrier to entry significantly while sidestepping that levy stack entirely.
ROI Example: If a local factory utilizes the Neural Nexus arm to automate a sorting process that previously required two shifts of human labor (saving approximately 100,000 LKR per month in combined wages, statutory contributions, and overtime premiums, alongside reduced defect rates), the factory achieves a complete Return on Investment (ROI) in under

### 15 months. This rapid payback period transitions the purchase from a risky CAPEX to a

highly attractive operational upgrade for risk-averse business owners.

# Chapter 9

# Marketing, Sales, and Beyond

## 9.1 Product Philosophy: A Precise Automation Skeleton

Neural Nexus is deliberately engineered as a general-purpose precise automation skeleton rather than a task-specific machine: a single, sub-millimeter-repeatable 6-DOF mechanical and control platform (Chapters 3–6) onto which a customer- or vertical-specific tool-head and perception stack can be mounted via the hot-swappable tool interface (Chapter 6). The base arm, MATLAB Digital Twin, and STM32H743VIT6 control stack never need to change between customers; only the end-effector and the Computer Vision (CV) model running on top of it are tailored. This philosophy underpins both target markets below and the industrial go-to-market strategy described later in this chapter.

## 9.2 Target Market

- Small & Medium Factories: Ideal for repetitive, high-turnover tasks such as food packaging, garment sorting, and electronics assembly where human error and fatigue are high.
- STEM Education: Providing universities, technical colleges, and pre-university STEM academies with an affordable, programmable platform to train students on modern robotics, directly feeding the local engineering talent pool. As described in Chapter 1, this segment is already commercially proven locally (STEM enrolment growing ∼10%/year, with an active private robotics-academy market), but is currently served only with imported hobbyist-grade kits.

### Anchor STEM Partnership

As proof of the education-market thesis, Neural Nexus has already reached agreement with a major Sri Lankan STEM education institute to deliver hands-on robotics sessions using the physical arm as part of their student programme. This is a deliberate first commercial deployment: it puts the arm in front of a large, recurring student cohort ahead of full-scale production, generates real usage data and testimonials to de-risk the wider education bundle described below, and gives the STEM partner’s students the same hands-on programmable 6-DOF access that Chapter 1 shows no other institution in the country currently offers.

## 9.3 Revenue Streams (The Ecosystem Model)

We are transitioning from a traditional hardware sales model to a highly lucrative “Robotics Ecosystem” model, ensuring both upfront capital and continuous Annual Recurring Revenue (ARR).

- Tier 1: Base Hardware Sales (CAPEX): 1,500,000 LKR upfront revenue per arm.
- Tier 2: Premium Hardware Add-ons:

– Bespoke End-Effectors (vacuums, customized grippers) priced between 45,000– 85,000 LKR.

– Industrial Touch HMI Console: A ruggedized, standalone Raspberry Pi-driven touch screen interface. This is sold as a premium operational upgrade (estimated at 150,000 LKR) for enterprise clients who require dedicated floor-level control kiosks without tethering a personal computer.

- Tier 3: SaaS (Software as a Service): Optional annual subscriptions to unlock advanced Computer Vision models, predictive maintenance analytics, and OTA (Over-The-Air) software updates.
- Service & Maintenance Contracts: Paid annual tiers for guaranteed 24/48-hour on-site robotic servicing and hardware checkups.

## 9.4 Sales Strategy & Go-To-Market

- Start Small to Prove Value (“Land and Expand”): We target a single bottleneck in a client’s factory, deploy one unit to prove the ROI in under 6 months, and then secure enterprise contracts to automate the rest of their fleet.
- Flexible Leasing (Robot as a Service): For businesses lacking the 1.5M LKR upfront capital, we offer a lease model, charging a monthly fee based on machine uptime. This turns a massive CAPEX into a manageable OPEX for the factory owner.
- Education Bundles: Providing subsidized starter kits to universities and STEM institutes (building on the anchor partnership above) ensures the next generation of engineers is already trained on, and biased toward, the Neural Nexus ecosystem when they enter the workforce.

### Industrial Go-To-Market: The “Trojan Horse” Strategy

Because the current unit is a Proof of Concept (POC) rather than a field-proven industrial product, Neural Nexus deliberately does not attempt to sell a generic, one-size-fits-all industrial arm on day one. Instead, the identical automation skeleton described in Section 9.1 is positioned as the carrier for a narrow, customer-specific solution:

- The arm is the constant; the head is the offer. For each pilot industrial customer, only the tool-head (gripper, vacuum end-effector, or custom fixture) and the CV model running the vision pipeline are engineered around that customer’s specific part geometry, defect signature, or sorting criterion—the underlying arm, control stack, and Digital Twin are unchanged.
- Why this is a “Trojan Horse”: The customer evaluates and buys what looks like a narrow, purpose-built solution to their specific bottleneck (e.g. “a machine that sorts these particular garment panels”), which is a far easier and faster sale than an abstract general-purpose robotic arm. Once the unit is installed and trusted on the factory floor, the same underlying skeleton is already capable of being re-tooled and re-trained for adjacent tasks, positioning Neural Nexus for the Land-and-Expand growth path above without a second capital sale.
- De-risking the POC-to-product transition: Because each early industrial deployment is scoped narrowly around one tailored head and one CV model, the engineering team can validate reliability and repeatability against a tight, well-defined success criterion per pilot, rather than needing the arm to be simultaneously excellent at every possible task before its first sale.

# Chapter 10

# Project Budget and Bill of Quantities (BOQ)

The figures below are drawn directly from the team’s running project finance tracker as of 18 July 2026, rather than an estimated cost model, and reflect actual funds pooled, donated, and spent to date.

## 10.1 Project Funding Summary

Item | Amount (LKR)
Total money pooled by team members | 333,361.00
Total donations received | 230,000.00
Combined project value (pooled + donated + member-covered deficit) | 568,982.27
Total money expensed to date | 338,982.27
Current remaining balance | −5,621.27

Table 10.1: Project funding summary, as of 18 July 2026

The small negative remaining balance indicates that actual expenditure has slightly exceeded the pooled and donated funds; this shortfall has been covered informally, out of pocket, by team members pending final reconciliation.

## 10.2 Donations Received

Donor | Asset Acquired | Amount (LKR)
Seniors (alumni) 2 × NEMA 24 motors | 160,000.00
A colleague | Aluminum sheet stock | 30,000.00
A colleague | Raspberry Pi + Pi Camera | 40,000.00
Total | | 230,000.00

Table 10.2: External and member-sourced donations, with the specific asset each funded

## 10.3 Expenditure Summary by Category

Category | Amount Spent (LKR)
Hardware components and sourcing (motors, drivers, bear- ings, fasteners, laser/rod cutting, 3D printing) | 237,856.27
PCB fabrication and components (JLCPCB, LCSC, encoder boards) | 72,486.00
Import tax and duties (component and PCB tax lines) | 13,730.00
Enclosure materials and cutting (plywood, frame, laser cutting) | 3,480.00
Transport and logistics | 1,700.00
Software subscriptions, fuel, and miscellaneous | 9,730.00
Total Money Expensed | 338,982.27

Table 10.3: Actual project expenditure to date, summarized by category from the finance tracker

Hardware sourcing and PCB fabrication together account for over 90% of expenditure to date, consistent with the prototype’s electronics- and motor-heavy Bill of Materials described in Chapter 2. [Placeholder: A fully itemized final budget accounting for volume-production pricing, shipping, and projected OPEX — distinct from this prototype-phase actuals tracker — will be provided in the final revision; see Chapter 8 for volume-production COGS estimates.]

## 10.4 Future Improvements and Monetization Strategies

To ensure long-term product viability and create new revenue verticals, several strategic improvements are slated for development:

- Dedicated Touch HMI Console (Premium Add-on): As detailed in our revenue streams, the current system relies on standard PC/terminal interfaces. Developing a rugged, standalone touch-screen HMI will allow us to immediately upsell enterprise clients who require robust, dedicated floor-level control kiosks.
- Edge AI Computer Vision Integration: Currently, real-time object tracking is verified through standard camera detection. We plan to implement the CV pipeline directly into a dedicated edge device (like a Raspberry Pi with an optimized camera module) mounted directly on the arm workspace. This unlocks untethered visual servoing, which will be offered as a premium SaaS tier for advanced quality control and dynamic sorting applications.
- Fleet Management Dashboard: A cloud-connected dashboard allowing enterprise customers with multiple units to monitor uptime, cycle counts, and predictivemaintenance alerts across their entire Neural Nexus fleet from a single pane of glass.

# Chapter 11

# Task Allocation Among Group Members

The execution of the Neural Nexus project relied on specialized, cross-functional collaboration, ensuring all engineering and business deliverables were met on schedule:

- Lasan Perera (Lead): Overall project management, systems integration, structural analysis, wiring, and industrial enclosure fabrication.
- Isitha Dinujaya: Computer Vision architecture, software integration, and supplementary 3D Design.
- Dulana Pitiwaduge: Hardware electronics architecture, component sourcing, custom PCB Design, and financial modeling.
- Deneth Priyadarshana: Primary 3D Design, structural analysis, and mechanical tolerancing for manufacturability.
- Mokshan Colombage: 3D Design, rendering, soldering, and business strategy alignment.

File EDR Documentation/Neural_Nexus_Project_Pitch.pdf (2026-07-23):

# NEURAL NEXUS Precision Automation


UNIVERSITY OF MORATUWA • ELECTRONIC DESIGN REALIZATION

An industrial-grade 6-DOF robotic ecosystem designed to liberate Sri Lankan manufacturing from restrictive import levies, currency inflation, and long-lead shipping delays.

### Sri Lanka's 1st SME Arm

100% locally serviceable, zero import delays, 24/7 technical support network.

# < 15 Months

SME PAYBACK PERIOD

# 2.0 kg

PAYLOAD CAPACITY

62%

GROSS OPERATING MARGIN

## Local Pricing, Premium Performance

Undercutting imported alternatives by over 33% at a strategic retail price of 1,500,000 LKR.

## True Sub-Millimeter Repeatability

Closed-loop feedback driven by an STM32H7 MCU and AS5047P absolute magnetic encoders.

## MATLAB Digital Twin & Edge AI

Pre-validated collision safety models and robust vision-guided pick-and-place tracking.

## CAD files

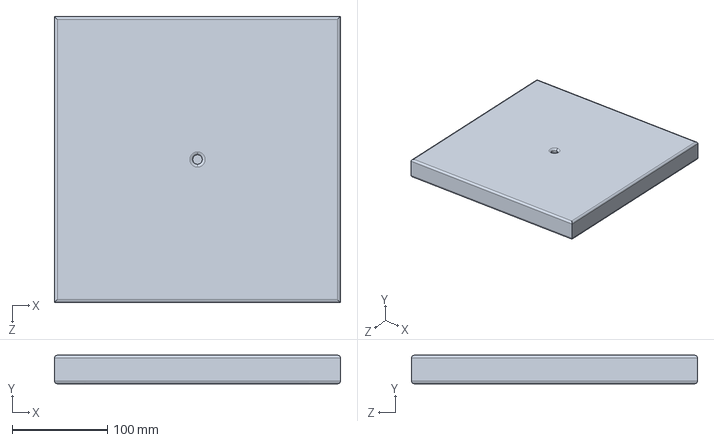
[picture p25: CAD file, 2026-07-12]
IK Simulation MATLAB/Part6_Default_sldprt.STEP
300.0 x 30.0 x 300.0 mm

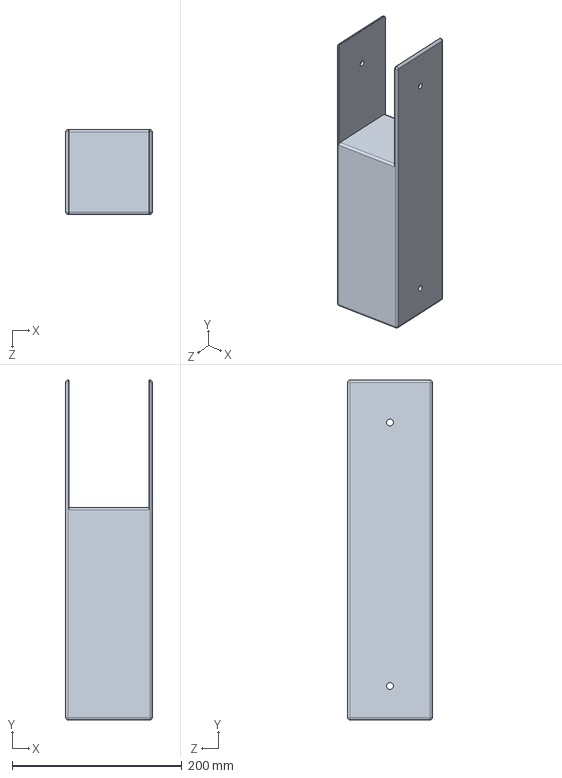
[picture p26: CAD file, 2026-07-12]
IK Simulation MATLAB/Part2_Default_sldprt.STEP
102.0 x 400.0 x 100.0 mm

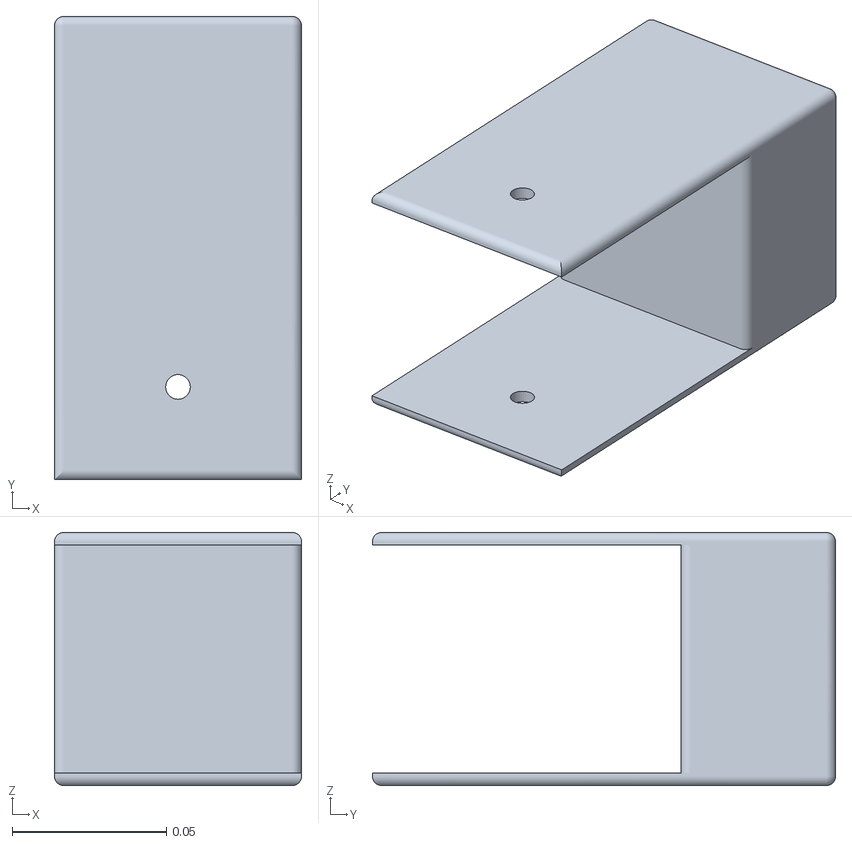
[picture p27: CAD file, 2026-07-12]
IK Simulation MATLAB/Part4.STL
0.08 x 0.15 x 0.082

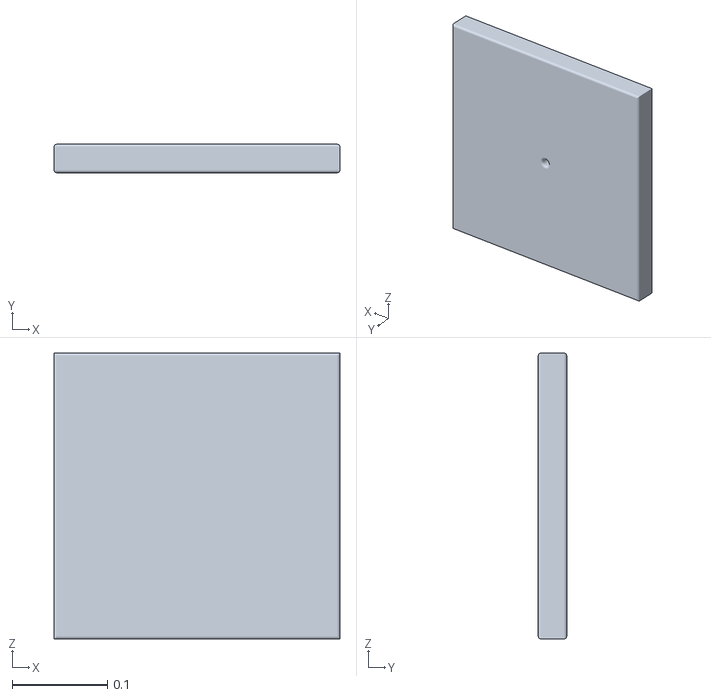
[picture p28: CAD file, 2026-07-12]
IK Simulation MATLAB/Part6.STL
0.3 x 0.03 x 0.3

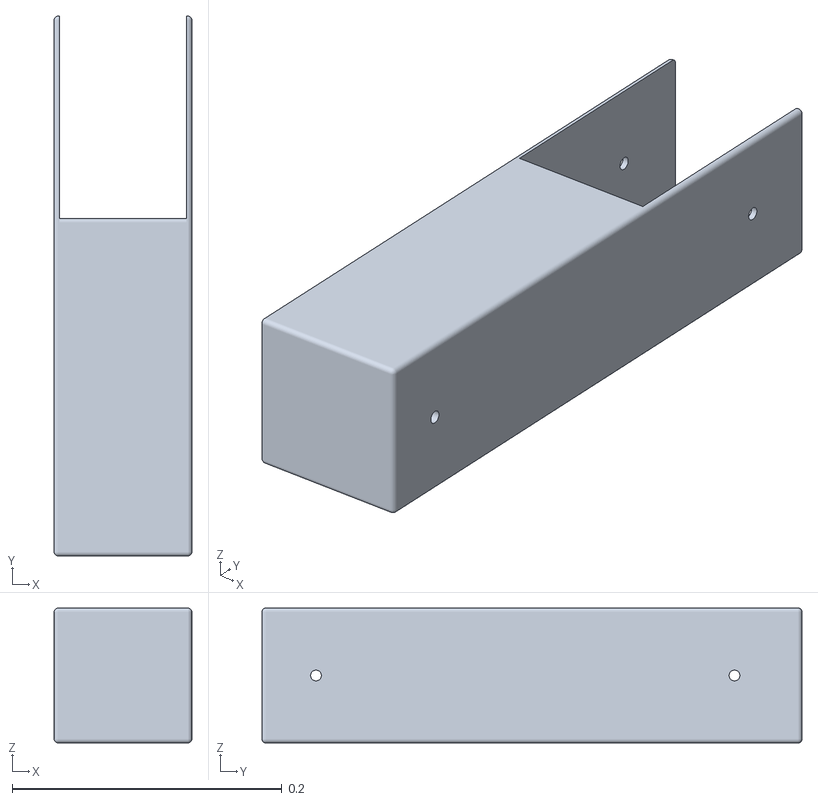
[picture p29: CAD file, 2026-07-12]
IK Simulation MATLAB/Part2.STL
0.102 x 0.4 x 0.1

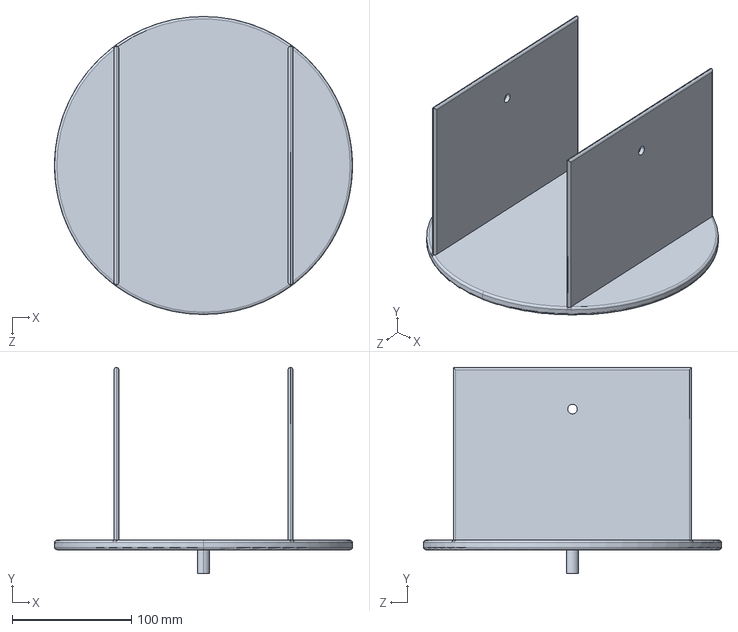
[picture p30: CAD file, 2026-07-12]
IK Simulation MATLAB/Part1_Default_sldprt.STEP
250.0 x 173.0 x 250.0 mm

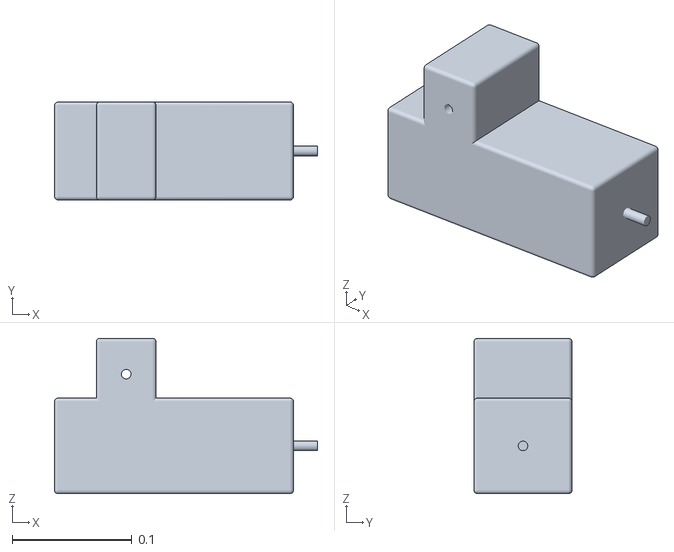
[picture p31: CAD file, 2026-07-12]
IK Simulation MATLAB/Part3.STL
0.22 x 0.082 x 0.13

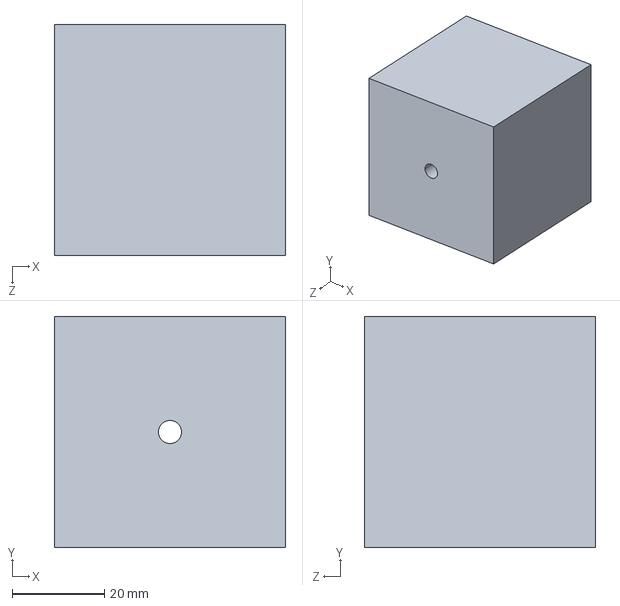
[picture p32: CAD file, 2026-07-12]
IK Simulation MATLAB/endeff_Default_sldprt.STEP
50.0 x 50.0 x 50.0 mm

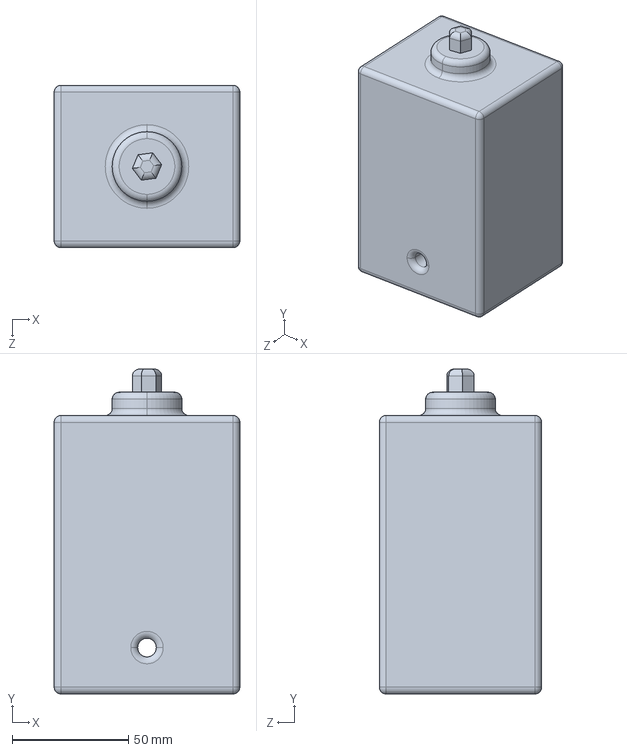
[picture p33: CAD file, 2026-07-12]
IK Simulation MATLAB/Part5_Default_sldprt.STEP
80.0 x 140.0 x 70.0 mm

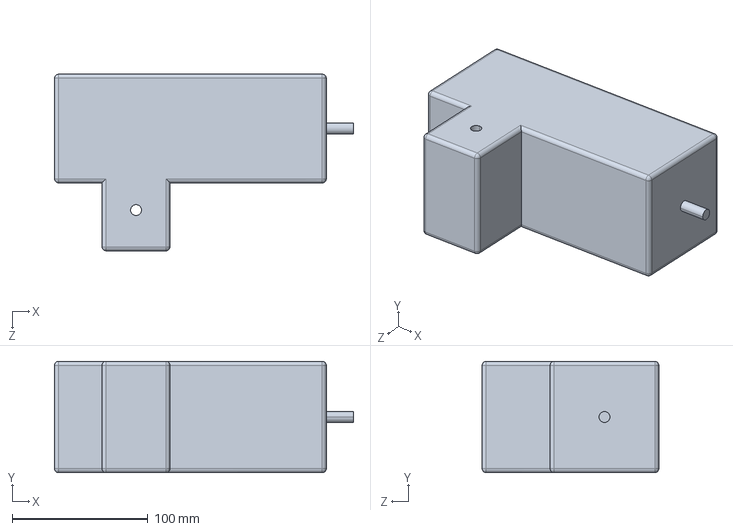
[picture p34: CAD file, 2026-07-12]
IK Simulation MATLAB/Part3_Default_sldprt.STEP
220.0 x 82.0 x 130.0 mm

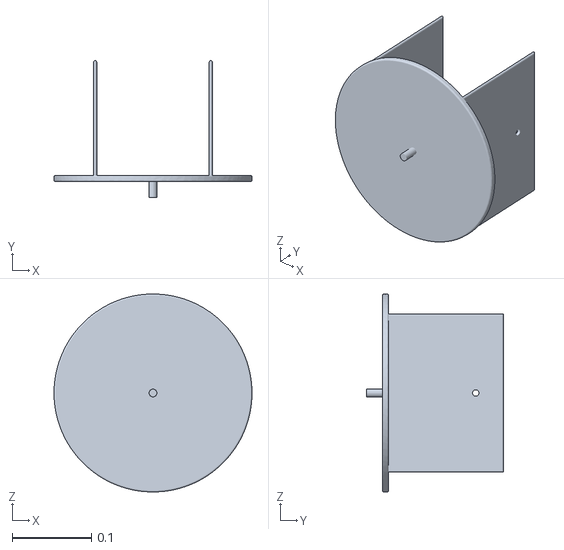
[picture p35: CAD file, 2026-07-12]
IK Simulation MATLAB/Part1.STL
0.25 x 0.173 x 0.25

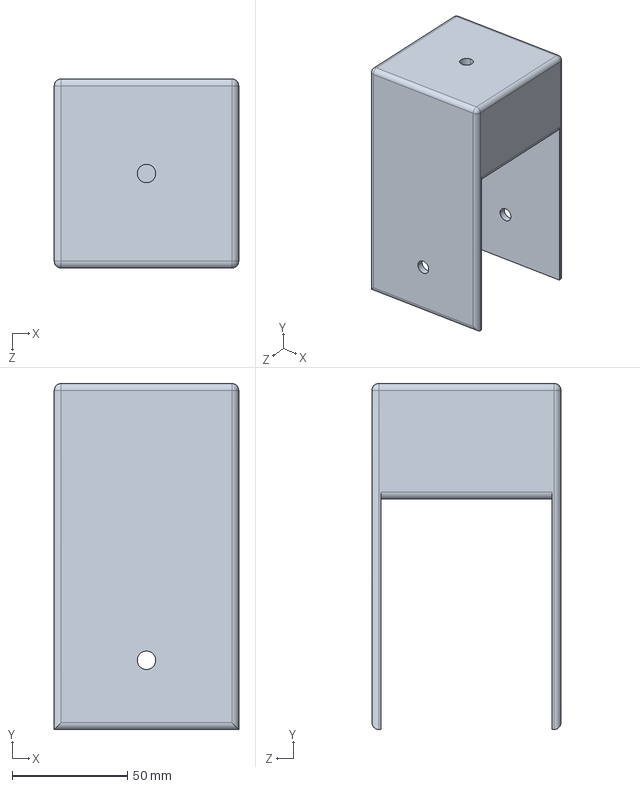
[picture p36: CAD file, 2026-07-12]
IK Simulation MATLAB/Part4_Default_sldprt.STEP
80.0 x 150.0 x 82.0 mm

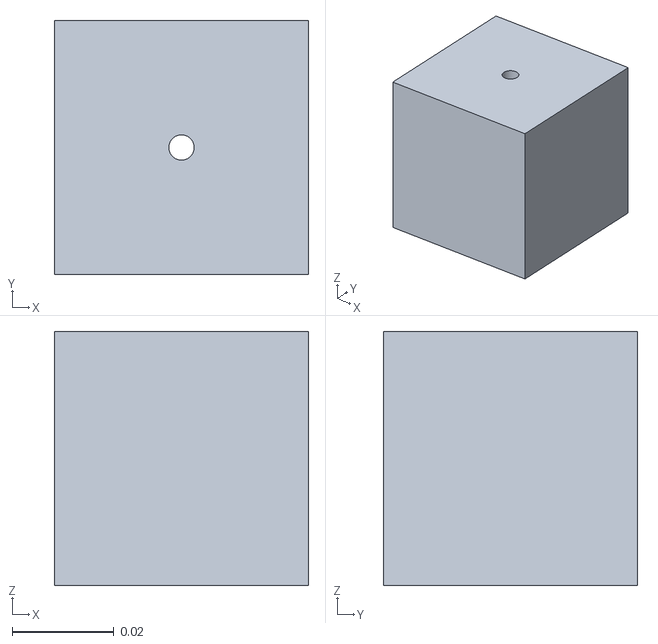
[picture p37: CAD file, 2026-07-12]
IK Simulation MATLAB/endeff.STL
0.05 x 0.05 x 0.05

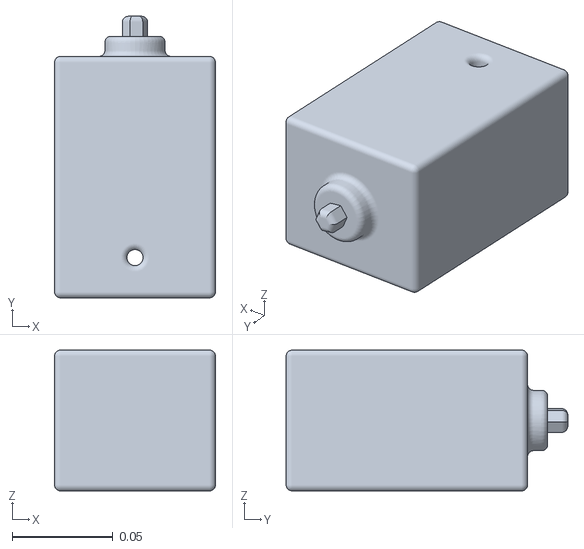
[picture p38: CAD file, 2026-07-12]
IK Simulation MATLAB/Part5.STL
0.08 x 0.14 x 0.07

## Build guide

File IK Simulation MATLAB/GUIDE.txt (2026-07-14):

==============================================================================
 NeuralNexusArm - MATLAB / Simulink Command Guide
==============================================================================
 Quick reference for running the 6-DOF arm: IK, the interactive tool,
 XYZ commands, hardware link, and the two demos.
 Keep this next to your MATLAB session.
==============================================================================

------------------------------------------------------------------------------
 0. ONE-TIME SETUP EACH SESSION  (run these first, in order)
------------------------------------------------------------------------------
% Load & build the robot model from the Simscape import
load_system('Assem1')
robot = importrobot('Assem1');
robot.DataFormat = 'row';

% Apply joint limits (J3 & J5 are on the 180-deg band)
limitsDeg = [ -180 180;   % J1
              -70   70;   % J2
              120  240;   % J3  (180 +/- 60)
              -180 180;   % J4
               60  300;   % J5  (180 +/- 120)
              -180 180 ]; % J6
for i = 1:6
    robot.Bodies{i}.Joint.PositionLimits = deg2rad(limitsDeg(i,:));
end

% Build the IK solver and the home reference
ik      = inverseKinematics('RigidBodyTree', robot);
weights = [1 1 1 1 1 1];
q0      = homeConfiguration(robot);
Thome   = getTransform(robot, q0, 'Body6');

% (Hardware only) open the serial link to the STM32
s = serialport("COM9", 115200);      % clear s;  to release it later

------------------------------------------------------------------------------
 1. FIND WHERE THE TIP IS NOW
------------------------------------------------------------------------------
Thome = getTransform(robot, q0, 'Body6');
tipHome = Thome(1:3,4)'               % [x y z] in METERS

------------------------------------------------------------------------------
 2. SOLVE IK FOR A TARGET POINT  (simulation only)
------------------------------------------------------------------------------
myTarget = [-0.25 0.30 0.05];         % desired tip position [x y z], METERS
target = trvec2tform(myTarget);
target(1:3,1:3) = Thome(1:3,1:3);     % keep home orientation
[qSol, info] = ik('Body6', target, weights, q0);
info.Status                           % 'success' = reachable
rad2deg(qSol)                         % the six joint angles (deg)
show(robot, qSol);                    % preview skeleton

------------------------------------------------------------------------------
 3. INTERACTIVE SLIDER TOOL  (drag X/Y/Z, live IK, Play button)
------------------------------------------------------------------------------
armIK(robot, ik, weights, q0)         % opens the control window

------------------------------------------------------------------------------
 4. SEND AN XYZ TO THE REAL ARM  (+ synced simulation)
------------------------------------------------------------------------------
% Requires: serial 's' open, firmware running, arm has clear space.
% goToXYZ solves IK, sends angles over USB, and loads jointData for Simulink.
goToXYZ(robot, ik, weights, q0, [-0.15 0.30 0.10], s)
% then press RUN in Simulink (StopTime = 5) to play the synced 3D twin.

% NOTE: firmware is in RELATIVE mode - each command is a delta from the
% arm's current pose. Keep targets modest until encoders are added.

------------------------------------------------------------------------------
 5. DEMOS  (simulation, for showing off)
------------------------------------------------------------------------------
% Both write 'jointData'. Run ONE function, then Run the sim and let it
% finish, THEN run the other. Blocks must read jointData columns 2-7.

% DEMO 1 - POSITION LOCK (tip point held, tool orientation sweeps, links flow)
demoPositionLock(robot, ik, q0)
%   -> Simulink StopTime = 12, then Run.

% DEMO 2 - ORIENTATION LOCK + X/Y/Z SWEEP (tool angle held, tip sweeps each axis)
demoOrientationLock_XYZsweep(robot, ik, q0)
%   -> Simulink StopTime = 15, then Run.

------------------------------------------------------------------------------
 6. DRIVE THE SOLID ARM IN MECHANICS EXPLORER MANUALLY
------------------------------------------------------------------------------
% After any function that builds 'jointData':
set_param('Assem1','StopTime','12')
set_param('Assem1','SimulationCommand','start')
pause(1)
get_param('Assem1','SimulationStatus')      % 'running' or 'stopped'

------------------------------------------------------------------------------
 7. HARDWARE - RAW SERIAL COMMANDS (bypass IK, send angles directly)
------------------------------------------------------------------------------
% Six comma-separated joint angles in degrees; firmware converts to steps.
writeline(s, "10,0,0,0,0,0")          % nudge J1
writeline(s, "0,10,0,0,0,0")          % nudge J2   ... etc
pause(0.1); readline(s)               % read the "steps: ..." echo back

------------------------------------------------------------------------------
 8. SIMULINK FROM WORKSPACE BLOCK MAP  (set each block's Data field)
------------------------------------------------------------------------------
   Revolute1  (J1)  ->  [jointData(:,1), jointData(:,2)]
   Revolute   (J2)  ->  [jointData(:,1), jointData(:,3)]
   Revolute2  (J3)  ->  [jointData(:,1), jointData(:,4)]
   Revolute3  (J4)  ->  [jointData(:,1), jointData(:,5)]
   Revolute4  (J5)  ->  [jointData(:,1), jointData(:,6)]
   Revolute5  (J6)  ->  [jointData(:,1), jointData(:,7)]

------------------------------------------------------------------------------
 QUICK TROUBLESHOOTING
------------------------------------------------------------------------------
- Sim "runs" but nothing moves:
    * StopTime too short -> set it to match the demo (5 / 12 / 15).
    * Target too close to home -> the glide is tiny; pick a farther point.
    * Blocks not reading jointData -> re-check the block map in section 8.
- Only one joint moves in sim -> a block still points at old test data.
- writeline error about 's' -> the serial port got overwritten; re-open:
    clear s;  s = serialport("COM9", 115200);
- Arm won't move on serial -> check firmware flashed & COM9 in Device Manager.
==============================================================================

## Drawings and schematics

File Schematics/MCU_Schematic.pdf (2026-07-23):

# SYSTEM RST

# SWITCHES

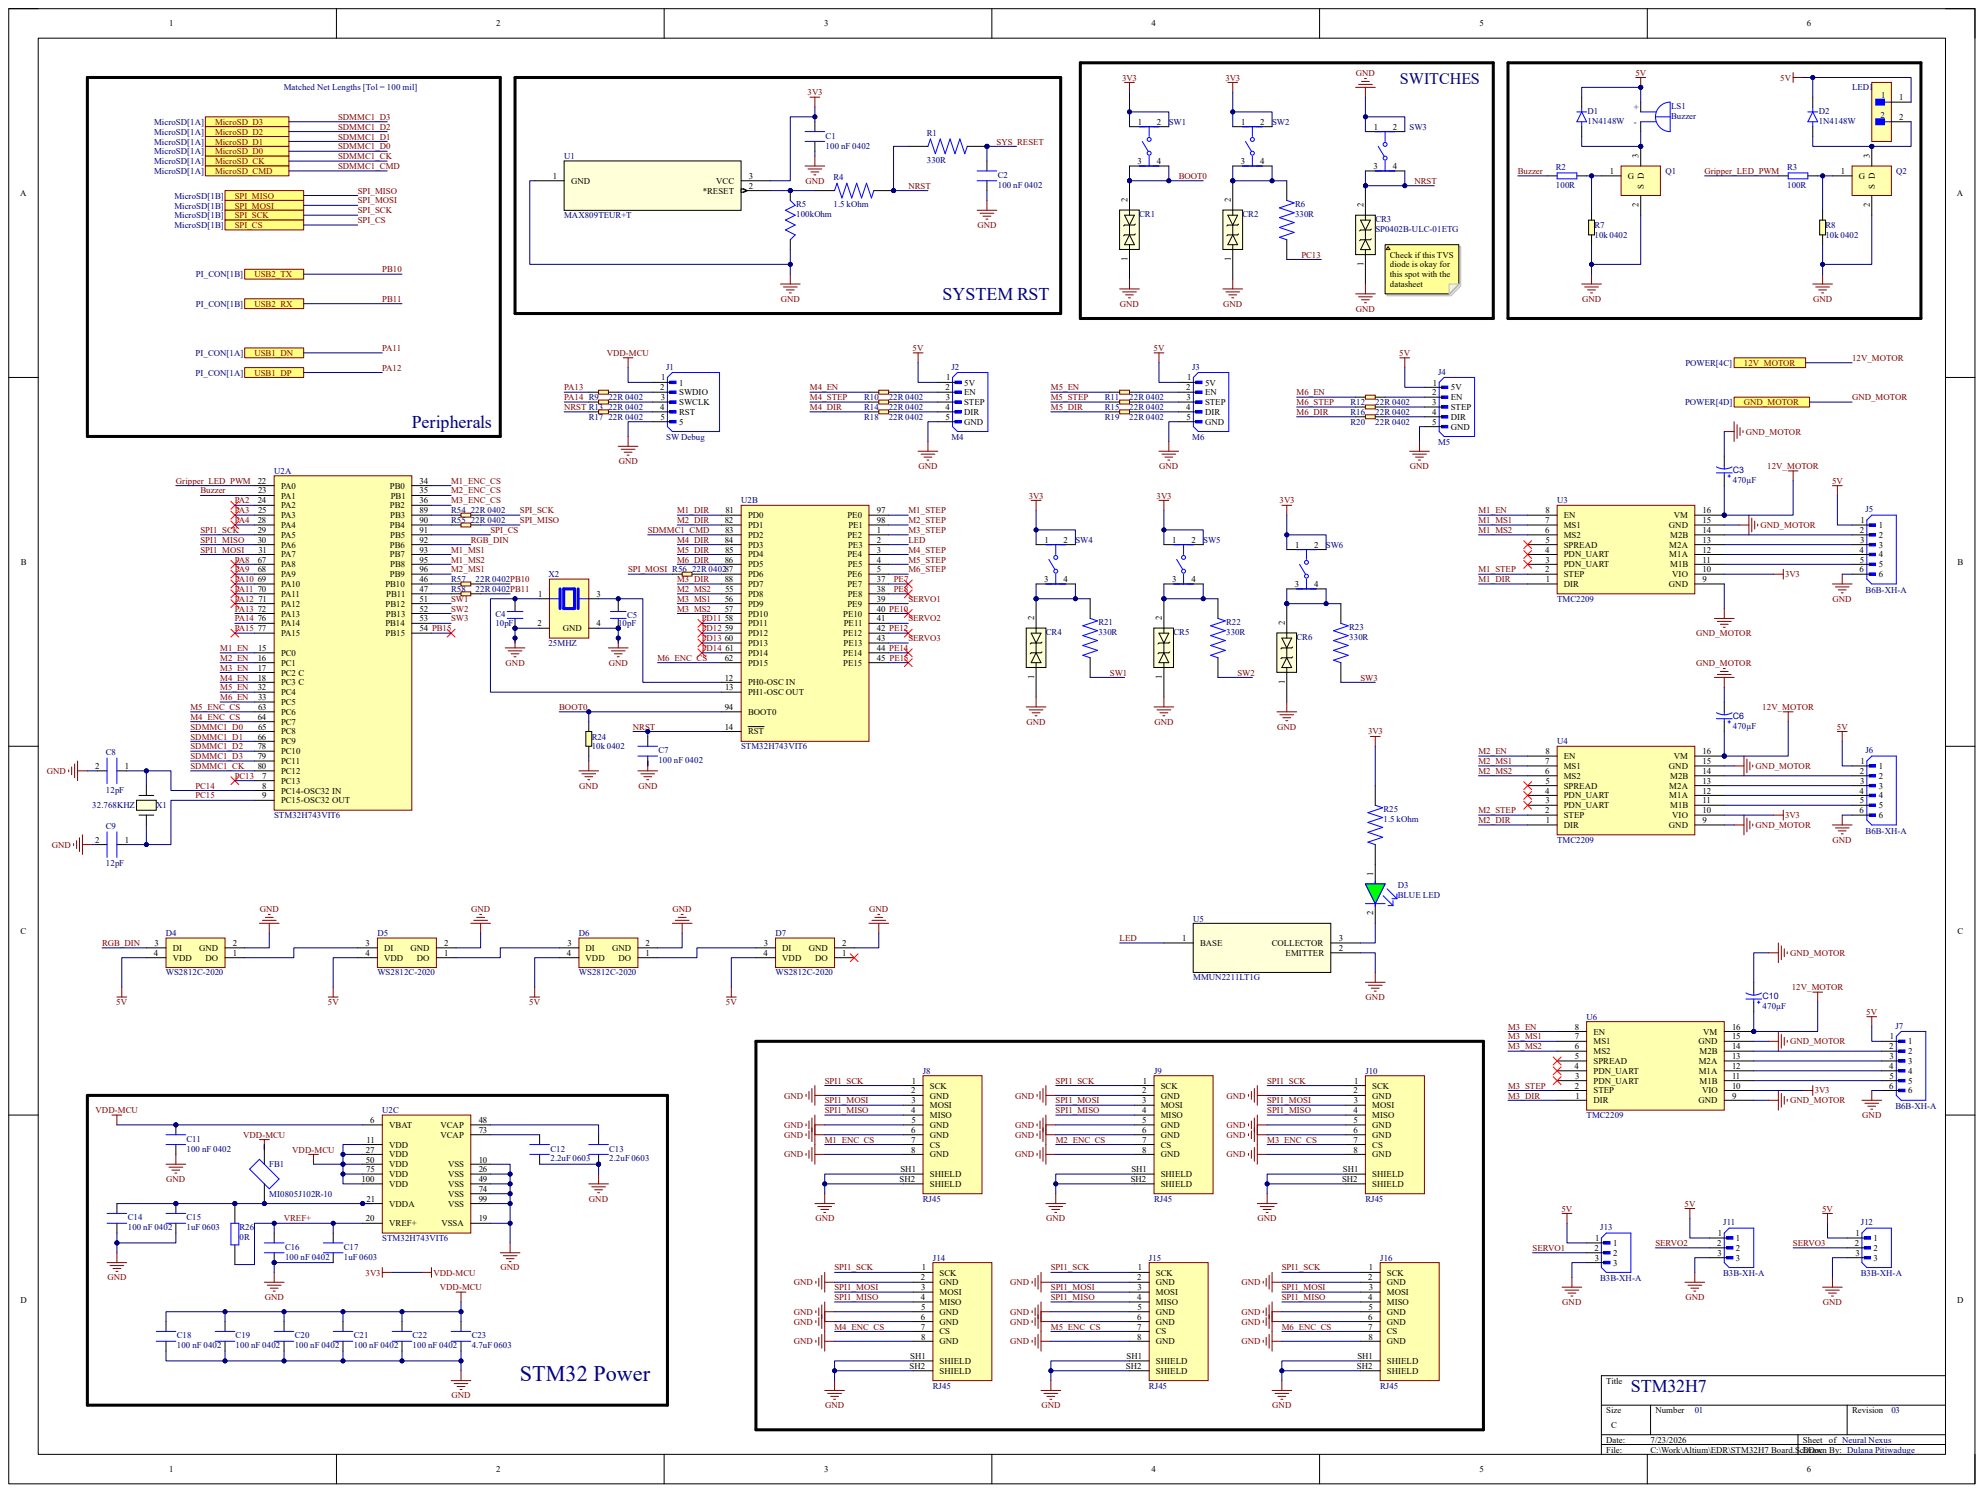
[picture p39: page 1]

Matched Net Lengths [Tol = 100 mil]

Check if this TVS
diode is okay for
this spot with the
datasheet

1

2

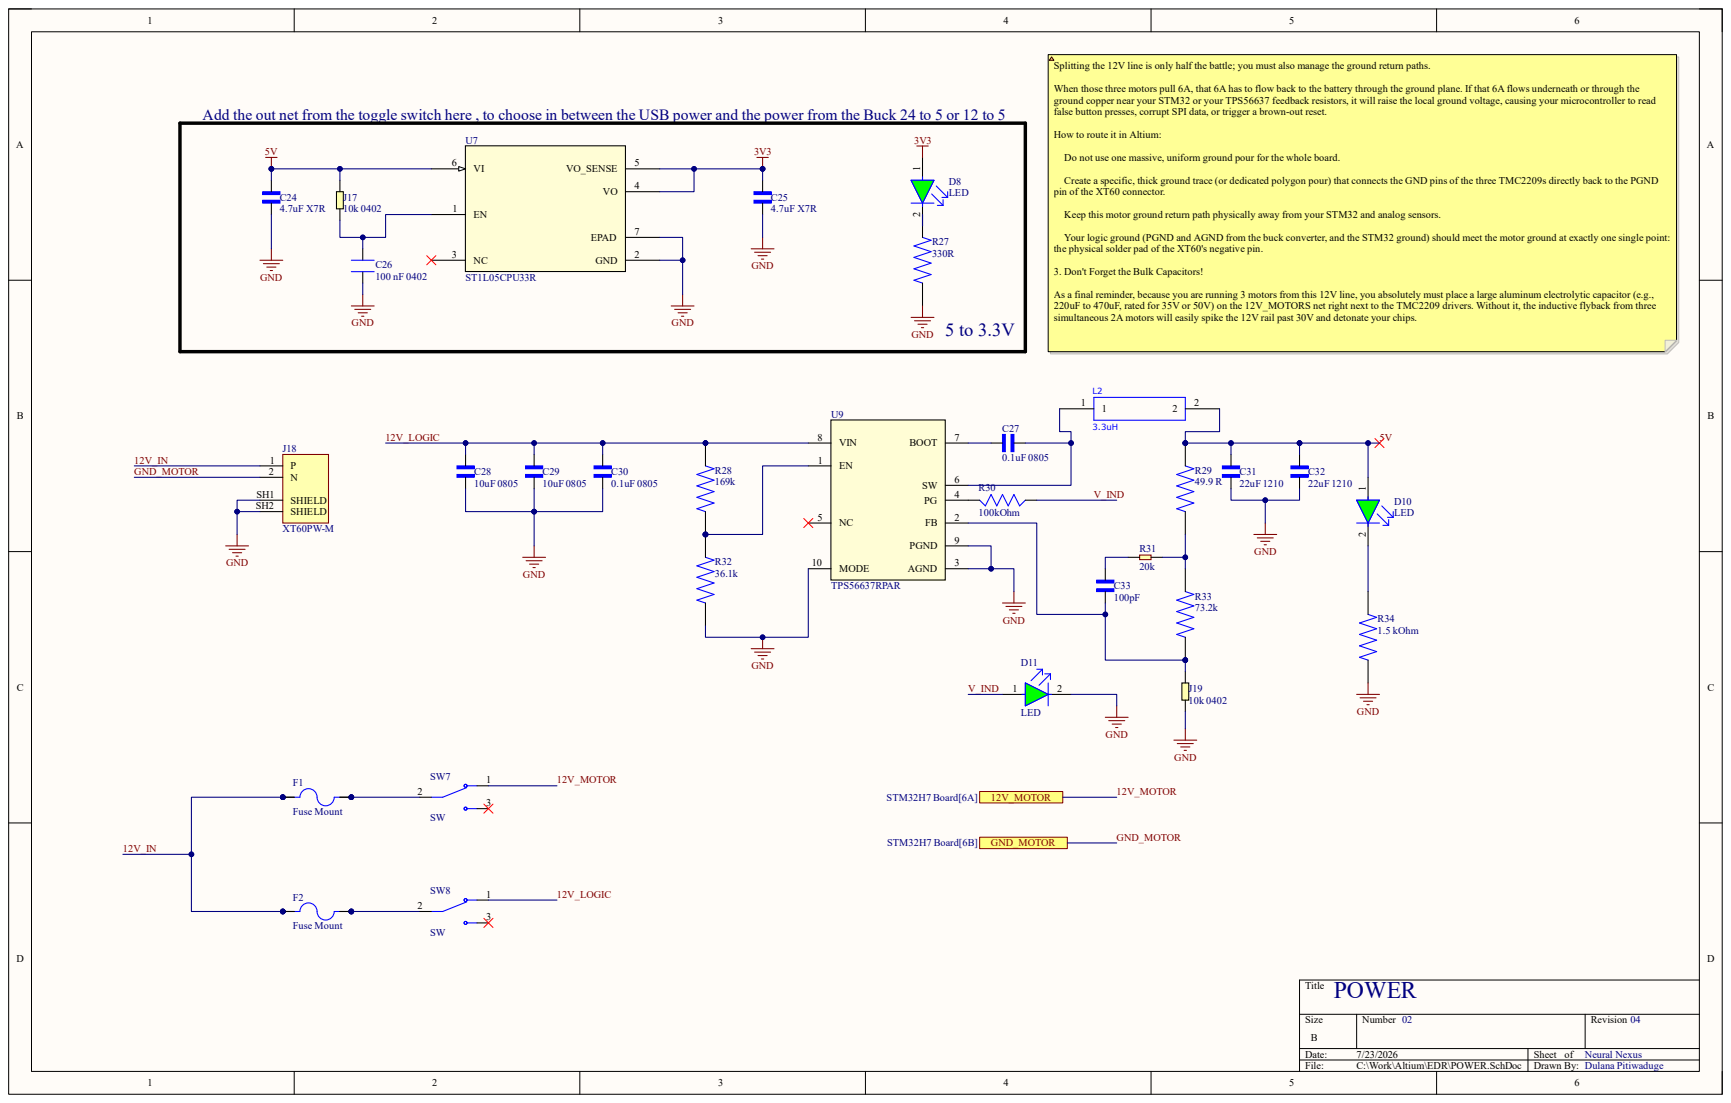
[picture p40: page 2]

Splitting the 12V line is only half the battle; you must also manage the ground return paths.

When those three motors pull 6A, that 6A has to flow back to the battery through the ground plane. If that 6A flows underneath or through the
ground copper near your STM32 or your TPS56637 feedback resistors, it will raise the local ground voltage, causing your microcontroller to read
false button presses, corrupt SPI data, or trigger a brown-out reset.

Add the out net from the toggle switch here , to choose in between the USB power and the power from the Buck 24 to 5 or 12 to 5

How to route it in Altium:

Do not use one massive, uniform ground pour for the whole board.

Create a specific, thick ground trace (or dedicated polygon pour) that connects the GND pins of the three TMC2209s directly back to the PGND
pin of the XT60 connector.

Keep this motor ground return path physically away from your STM32 and analog sensors.

Your logic ground (PGND and AGND from the buck converter, and the STM32 ground) should meet the motor ground at exactly one single point:
the physical solder pad of the XT60's negative pin.

3. Don't Forget the Bulk Capacitors!

As a final reminder, because you are running 3 motors from this 12V line, you absolutely must place a large aluminum electrolytic capacitor (e.g.,
220uF to 470uF, rated for 35V or 50V) on the 12V_MOTORS net right next to the TMC2209 drivers. Without it, the inductive flyback from three
simultaneous 2A motors will easily spike the 12V rail past 30V and detonate your chips.

1

2

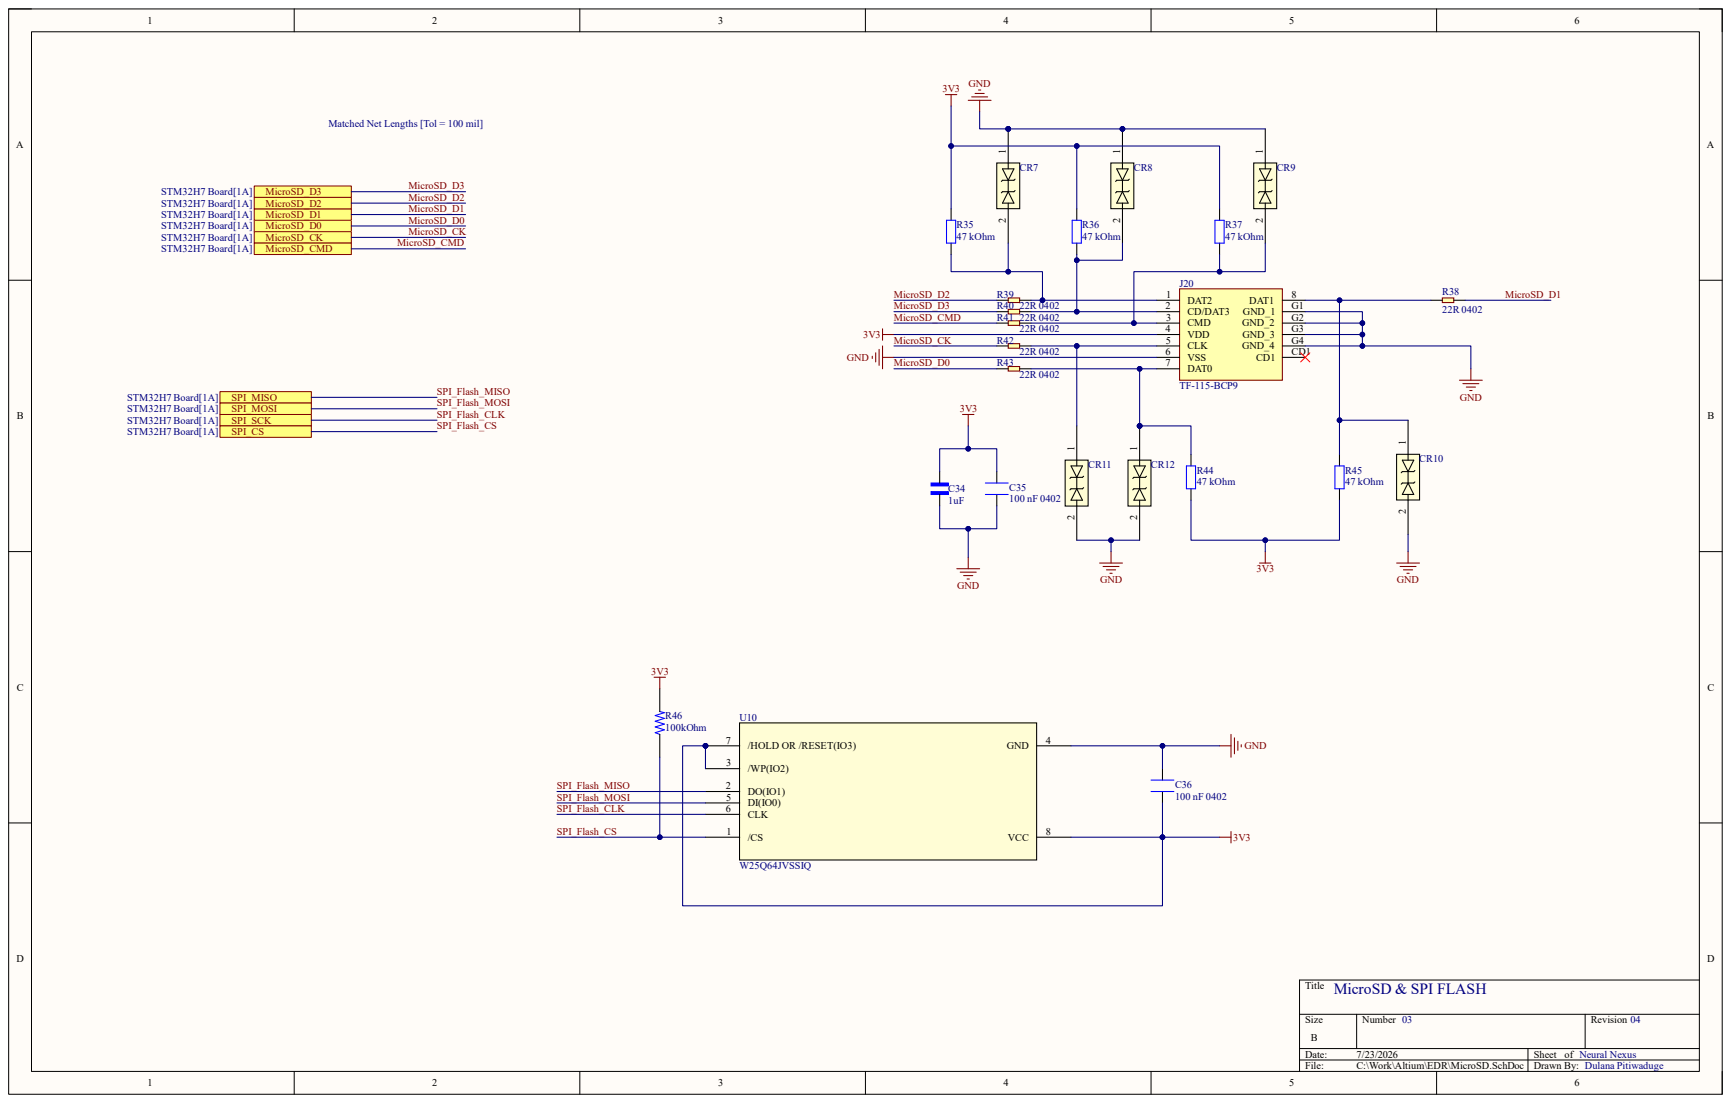
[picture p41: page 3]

Matched Net Lengths [Tol = 100 mil]

1

2

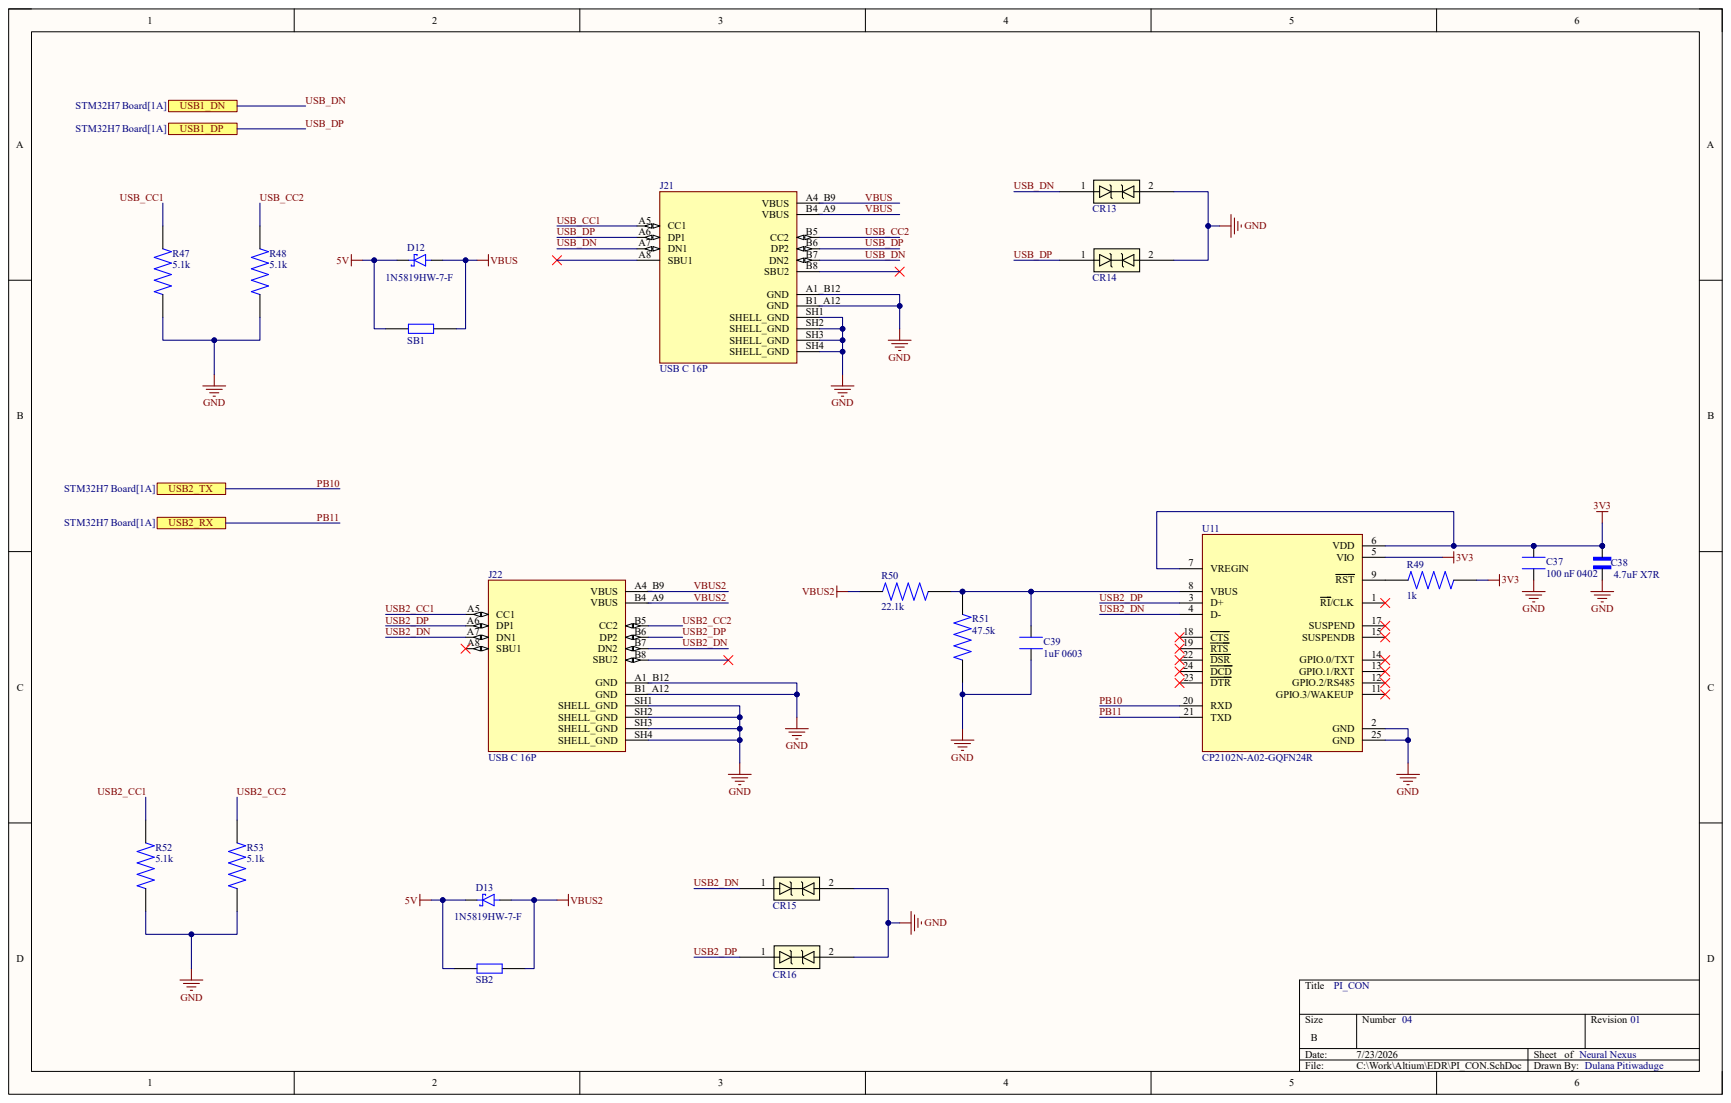
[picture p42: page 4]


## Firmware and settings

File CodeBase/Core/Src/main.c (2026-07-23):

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
/* Includes ------------------------------------------------------------------*/
#include "main.h"
#include "fatfs.h"
#include "usb_device.h"

/* USER CODE BEGIN Includes */
#include <math.h>
#include <stdbool.h>
#include "usbd_cdc_if.h"
#include <string.h>
#include <stdio.h>
/* USER CODE END Includes */


SD_HandleTypeDef hsd1;

SPI_HandleTypeDef hspi1;
SPI_HandleTypeDef hspi3;
DMA_HandleTypeDef hdma_spi1_rx;
DMA_HandleTypeDef hdma_spi1_tx;

TIM_HandleTypeDef htim1;
TIM_HandleTypeDef htim2;
TIM_HandleTypeDef htim6;

UART_HandleTypeDef huart3;

/* USER CODE BEGIN PV */
typedef struct {
	int32_t position;
	int32_t target;

	float speed;
	float maxSpeed;
	float acceleration;

	uint32_t stepInterval;
	uint32_t stepCounter;

	GPIO_TypeDef *STEP_Port;
	uint16_t STEP_Pin;

	GPIO_TypeDef *DIR_Port;
	uint16_t DIR_Pin;

	bool pulsePending; // STEP pin is HIGH, needs clearing at start of next tick

	int8_t encStepSign;

} Stepper_t;

Stepper_t motors[6];

/* ---- Per-joint configuration, all in JOINT order J1..J6 (base -> tip) ---- */

/* Joint (base -> tip) to motor-slot mapping. motors[] is 0-indexed: M1=0 .. M6=5.
 *   J1 Base rotation   -> M6 -> motors[5]
 *   J2 2nd link        -> M4 -> motors[3]
 *   J3 3rd link        -> M5 -> motors[4]
 *   J4 4th joint       -> M2 -> motors[1]
 *   J5 5th joint       -> M1 -> motors[0]
 *   J6 End effector rot-> M3 -> motors[2]                                     */
const uint8_t jointToMotor[6] = { 5, 3, 4, 1, 0, 2 };
const int8_t jointDir[6] = { -1, 1, -1, 1, 1, 1 };   // all positive for now

/* Per-joint speed & acceleration (steps/s and steps/s^2). Tune each link. */
const float jointMaxSpeed[6] = { 400, 400, 400, 400, 400, 400 };
const float jointAccel[6] = { 150, 150, 150, 150, 150, 150 };

/* Pulses per JOINT revolution (pulses/motor-rev × gear ratio), J1..J6 */
const float pulsesPerJointRev[6] = { 2800, 5000, 5000, 6400, 1600, 1600 };

/* Joint angle offsets (deg): software zero -> your CAD/model zero.
 J3 and J5 live on the 180°-centered band, so subtract 180 here. */
const float jointOffsetDeg[6] = { 0, 0, 180, 0, 180, 0 };

extern volatile uint8_t rxFlag;
extern char rxTemp[128];

/* Encoder CS pin per JOINT (J1..J6) */
GPIO_TypeDef *encCSPort[6] = { M6_ENC_CS_GPIO_Port, M4_ENC_CS_GPIO_Port,
M5_ENC_CS_GPIO_Port, M2_ENC_CS_GPIO_Port,
M1_ENC_CS_GPIO_Port, M3_ENC_CS_GPIO_Port };
const uint16_t encCSPin[6] = { M6_ENC_CS_Pin, M4_ENC_CS_Pin,
M5_ENC_CS_Pin, M2_ENC_CS_Pin,
M1_ENC_CS_Pin, M3_ENC_CS_Pin };

float encAngle[6] = { 0 }; /* latest encoder angle per joint, degrees */

uint16_t encRawPrev[6] = { 0 };      // last raw 14-bit reading per joint
int32_t encTicks[6] = { 0 };      // cumulative signed ticks per joint
uint8_t encInit[6] = { 0 };      // has the first reading been taken?

int32_t motorEncTicks[6] = { 0 };   // cumulative signed ticks, indexed by MOTOR
uint16_t motorEncRaw[6] = { 0 };   // last raw reading, per motor
uint8_t motorEncInit[6] = { 0 };   // first-read flag, per motor

#define CAP_MAX 10000
int32_t capTicks[CAP_MAX][6];   // encoder ticks per sample, per motor
uint16_t capCount = 0;           // how many samples captured
uint8_t capturing = 0;          // 1 while recording

/* Home reference — absolute encoder angle (deg) at the home pose */
const float homeAngle[6] = { 356.36f, 221.75f, 193.63f, 349.88f, 148.61f,
		347.36f };

/* Motor pulses per ENCODER revolution (before joint gearing).
 J4/J5/J6 are 1:1 so = pulsesPerJointRev. J1/J2/J3: motor pulses per
 one encoder turn. ADJUST J1/J2/J3 to your real motor-side pulses/rev. */
const float pulsesPerEncRev[6] = { 400, 2000, 2000, 1600, 1600, 1600 };

/* USER CODE END PV */

void SystemClock_Config(void);
static void MPU_Config(void);
static void MX_GPIO_Init(void);
static void MX_DMA_Init(void);
static void MX_TIM6_Init(void);
static void MX_SPI1_Init(void);
static void MX_TIM1_Init(void);
static void MX_USART3_UART_Init(void);
static void MX_TIM2_Init(void);
static void MX_SDMMC1_SD_Init(void);
static void MX_SPI3_Init(void);
/* USER CODE BEGIN PFP */
void Stepper_InitAll(void);
void Stepper_SetEnableM1M2M3(bool enable);
void Stepper_SetEnableM4M5M6(bool enable);
void Stepper_Update(Stepper_t *m);
void Stepper_MoveAll(int32_t steps[6]);
void Stepper_MoveAllJoints(int32_t jointSteps[6]);
uint8_t Stepper_AnyMoving(void);
void HAL_TIM_PeriodElapsedCallback(TIM_HandleTypeDef *htim);
void Buzzer_SetFreq(uint32_t freq);
void AS5047P_ClearError(void);
float AS5047P_ReadJoint(uint8_t j);
void Encoders_ReadAll(void);
void AS5047P_ClearErrorCS(uint8_t j);
uint16_t AS5047P_ReadRaw(uint8_t j);
void Encoder_UpdateTicks(uint8_t j);
void Gripper_Init(void);
void Gripper_Open(void);
void Gripper_Close(void);
void Motor_UpdateEncoder(uint8_t m);
void Home_All(void);
void Encoder_Test30(void);
static uint16_t AS5047P_SPITransfer(uint8_t j, uint16_t tx);
/* USER CODE END PFP */

/**
  * @brief  The application entry point.
  * @retval int
  */
int main(void)
{

  /* MPU Configuration--------------------------------------------------------*/
  MPU_Config();

  /* MCU Configuration--------------------------------------------------------*/

  /* Reset of all peripherals, Initializes the Flash interface and the Systick. */
  HAL_Init();

  /* Configure the system clock */
  SystemClock_Config();

  /* USER CODE BEGIN SysInit */
	HAL_PWREx_EnableUSBVoltageDetector();

	RCC_PeriphCLKInitTypeDef PeriphClkInit = { 0 };
	PeriphClkInit.PeriphClockSelection = RCC_PERIPHCLK_USB;
	PeriphClkInit.UsbClockSelection = RCC_USBCLKSOURCE_HSI48;
	if (HAL_RCCEx_PeriphCLKConfig(&PeriphClkInit) != HAL_OK) {
		Error_Handler();
	}

  /* USER CODE END SysInit */

  /* Initialize all configured peripherals */
  MX_GPIO_Init();
  MX_DMA_Init();
  MX_TIM6_Init();
  MX_SPI1_Init();
  MX_TIM1_Init();
  MX_USART3_UART_Init();
  MX_TIM2_Init();
  MX_USB_DEVICE_Init();
//  MX_SDMMC1_SD_Init();
  MX_SPI3_Init();
//  MX_FATFS_Init();
  /* USER CODE BEGIN 2 */
	Stepper_InitAll();
	Stepper_SetEnableM1M2M3(true); // enable M1, M2, M3 (onboard TMC2209) drivers before moving
	Stepper_SetEnableM4M5M6(false); // enable M4, M5, M6 (external CL57T/CL57T/DM542) drivers before moving
	HAL_TIM_Base_Start_IT(&htim6);

	// Test: move ONE joint at a time to verify mapping/direction.

	int32_t jointSteps[6] = { 0, 0, 0, 0, 0, 0 };
	Stepper_MoveAllJoints(jointSteps);

	HAL_TIM_PWM_Start(&htim2, TIM_CHANNEL_2);
	Gripper_Init();

	for (uint8_t j = 0; j < 6; j++)
		HAL_GPIO_WritePin(encCSPort[j], encCSPin[j], GPIO_PIN_SET); // all CS idle high

  /* USER CODE END 2 */

  /* Infinite loop */
  /* USER CODE BEGIN WHILE */
	uint32_t lastEncPrint = 0;

	while (1) {

//		__HAL_TIM_SET_COMPARE(&htim1, TIM_CHANNEL_1, 1000);
//		HAL_Delay(2000);
//
//		__HAL_TIM_SET_COMPARE(&htim1, TIM_CHANNEL_1, 2000);
//		HAL_Delay(2000);
//		Gripper_Open();
////
//		HAL_Delay(500);
//
//		Gripper_Close();
//
//		HAL_Delay(500);
//
//		Gripper_Open();
//	  while(1){
//		  HAL_GPIO_TogglePin(LED_GPIO_Port, LED_Pin);
//		  HAL_Delay(500);   // 500 ms on, 500 ms off → 1 Hz blink
//
//	  }

//	  for (uint8_t j = 0; j < 6; j++) Encoder_UpdateTicks(j);

		if (rxFlag) {
			rxFlag = 0;
			if (strncmp(rxTemp, "HOME", 4) == 0) {
				Home_All();
				HAL_GPIO_WritePin(LED_GPIO_Port, LED_Pin, GPIO_PIN_SET);
			}
			else if (strncmp(rxTemp, "TEST", 4) == 0) {
				Encoder_Test30();
			}
			else if (rxTemp[0] == 'G' && rxTemp[1] == ',') {   // <-- flat, no nested rxFlag
				if (rxTemp[2] == '1')
					Gripper_Close();
				else
					Gripper_Open();
			}
			else {
				HAL_GPIO_WritePin(LED_GPIO_Port, LED_Pin, GPIO_PIN_SET);
				float ang[6] = { 0 };
				int n = sscanf(rxTemp, "%f,%f,%f,%f,%f,%f", &ang[0], &ang[1],
						&ang[2], &ang[3], &ang[4], &ang[5]);
				if (n == 6) {
					int32_t jointSteps[6];
					for (int j = 0; j < 6; j++)
						jointSteps[j] = (int32_t) lroundf(
								pulsesPerJointRev[j] * ang[j] / 360.0f);
					for (int k = 0; k < 6; k++)
						motors[k].position = 0;
					capCount = 0;
					capturing = 1;
					Stepper_MoveAllJoints(jointSteps);
				}
			}
		}
//
////		 when motion finishes, stop capturing and dump the whole buffer
//		if (capturing && !Stepper_AnyMoving()) {
//			capturing = 0;
//			for (uint16_t r = 0; r < capCount; r++) {
//				char msg[96];
//				int len = snprintf(msg, sizeof(msg),
//						"%u,%ld,%ld,%ld,%ld,%ld,%ld\r\n", r,
//						(long) capTicks[r][0], (long) capTicks[r][1],
//						(long) capTicks[r][2], (long) capTicks[r][3],
//						(long) capTicks[r][4], (long) capTicks[r][5]);
//				CDC_Transmit_FS((uint8_t*) msg, len);
//				HAL_Delay(2);           // let each USB packet flush
//			}
//			CDC_Transmit_FS((uint8_t*) "END\r\n", 5);
//		}

//		static uint32_t last = 0;
//
//		if (HAL_GetTick() - last >= 200) {
//			last = HAL_GetTick();
//
//			char msg[300];
//			int len = snprintf(msg, sizeof(msg), "enc |");
//
//			for (uint8_t j = 0; j < 6; j++) {
//				if (j==3){
//					uint16_t raw = AS5047P_ReadRaw(j);
//					float angle = AS5047P_ReadJoint(j);
//
//					if ((raw == 0xFFFF) || (angle < 0.0f)) {
//						len += snprintf(msg + len, sizeof(msg) - len,
//								" J%d:raw=ERR ang=---", j + 1);
//					} else {
//						len += snprintf(msg + len, sizeof(msg) - len,
//								" J%d:raw=%u ang=%.2f", j + 1, raw, angle);
//					}
//
//				}
//
//			}
//
//			len += snprintf(msg + len, sizeof(msg) - len, "\r\n");
//
//			CDC_Transmit_FS((uint8_t*) msg, len);
//		}

    /* USER CODE END WHILE */

    /* USER CODE BEGIN 3 */
	}
  /* USER CODE END 3 */
}

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
/* USER CODE BEGIN 4 */

void Encoder_Test30(void) {
	uint8_t j = 5;                       // J6
	uint8_t m = jointToMotor[j];
	char msg[100];

	// --- averaged read BEFORE ---
	float sum = 0;
	int cnt = 0;
	for (int t = 0; t < 20; t++) {
		float v = AS5047P_ReadJoint(j);
		if (v >= 0) {
			sum += v;
			cnt++;
		}
	}
	if (cnt == 0) {
		CDC_Transmit_FS((uint8_t*) "no read\r\n", 9);
		return;
	}
	float before = sum / cnt;

	// --- command exactly 30 deg worth of steps ---
	int32_t step = (int32_t) lroundf(30.0f * pulsesPerEncRev[j] / 360.0f); // 30 deg -> steps
	int32_t stepsMotor[6] = { 0 };
	stepsMotor[m] = step;         // positive; flip sign to test other direction
	motors[m].position = 0;
	Stepper_MoveAll(stepsMotor);
	while (Stepper_AnyMoving()) {
	}
	HAL_Delay(100);                      // let it settle

	// --- averaged read AFTER ---
	sum = 0;
	cnt = 0;
	for (int t = 0; t < 20; t++) {
		float v = AS5047P_ReadJoint(j);
		if (v >= 0) {
			sum += v;
			cnt++;
		}
	}
	if (cnt == 0) {
		CDC_Transmit_FS((uint8_t*) "no read2\r\n", 10);
		return;
	}
	float after = sum / cnt;

	// --- shortest signed encoder change ---
	float delta = after - before;
	while (delta > 180.0f)
		delta -= 360.0f;
	while (delta < -180.0f)
		delta += 360.0f;

	int L =
			snprintf(msg, sizeof(msg),
					"before=%.2f after=%.2f | commanded=30.0 measured=%.2f | steps=%ld\r\n",
					before, after, delta, (long) step);
	CDC_Transmit_FS((uint8_t*) msg, L);
}

void Home_J6(void) {
	uint8_t j = 5;                      // J6
	uint8_t m = jointToMotor[j];        // Corresponding motor

	//---------------- Get average encoder reading ----------------//

	float sum = 0.0f;
	uint8_t count = 0;

	for (int i = 0; i < 20; i++) {
		float angle = AS5047P_ReadJoint(j);

		if (angle >= 0.0f) {
			sum += angle;
			count++;
		}
	}

	// No valid readings
	if (count == 0)
		return;

	float now = sum / (float) count;

	//---------------- Calculate shortest angular error ------------//

	float errDeg = homeAngle[j] - now;

	while (errDeg > 180.0f)
		errDeg -= 360.0f;

	while (errDeg < -180.0f)
		errDeg += 360.0f;

	//---------------- Already at home ? --------------------------//

	if (fabsf(errDeg) < 1.0f)
		return;

	//---------------- Convert angle -> motor steps ----------------//

	int32_t step = (int32_t) lroundf(
			motors[m].encStepSign * errDeg * pulsesPerEncRev[j] / 360.0f);

	//---------------- Move the motor ------------------------------//

	int32_t stepsMotor[6] = { 0 };

	stepsMotor[m] = step;

	motors[m].position = 0;
	motors[m].target = 0;

	Stepper_MoveAll(stepsMotor);

	//---------------- Debug message -------------------------------//

	char msg[200];

	int len = snprintf(msg, sizeof(msg),

	"now=%.2f\r\n"
			"err=%.2f\r\n"
			"encSign=%d\r\n"
			"step=%ld\r\n",

	now, errDeg, motors[m].encStepSign, (long) step);

	CDC_Transmit_FS((uint8_t*) msg, len);
}




//5th joint
void Home_J5(void)
{
   uint8_t j = 4;                      // J5
   uint8_t m = jointToMotor[j];        // Corresponding motor

   //---------------- Get average encoder reading ----------------//

   float sum = 0.0f;
   uint8_t count = 0;

   for (int i = 0; i < 20; i++)
   {
       float angle = AS5047P_ReadJoint(j);

       if (angle >= 0.0f)
       {
           sum += angle;
           count++;
       }
   }

   // No valid readings
   if (count == 0)
       return;

   float now = sum / (float)count;


   //---------------- Calculate angle to DECREASE ----------------//

   float errDeg;

   if (now >= homeAngle[j])
   {
       errDeg = now - homeAngle[j];
   }
   else
   {
       errDeg = now + (360.0f - homeAngle[j]);
   }


   //---------------- Already at home ? --------------------------//

   if (fabsf(errDeg) < 1.0f)
       return;


   //---------------- Convert angle -> motor steps ----------------//

   int32_t step = (int32_t)lroundf(
           motors[m].encStepSign *
           (-errDeg) *
           pulsesPerEncRev[j] /
           360.0f);


   //---------------- Move the motor ------------------------------//

   int32_t stepsMotor[6] = {0};

   stepsMotor[m] = step;

   motors[m].position = 0;
   motors[m].target = 0;

   Stepper_MoveAll(stepsMotor);


   //---------------- Debug message -------------------------------//

   char msg[200];

   int len = snprintf(msg,
                      sizeof(msg),
                      "now=%.2f\r\n"
                      "home=%.2f\r\n"
                      "err=%.2f\r\n"
                      "encSign=%d\r\n"
                      "step=%ld\r\n",
                      now,
                      homeAngle[j],
                      errDeg,
                      motors[m].encStepSign,
                      (long)step);

   CDC_Transmit_FS((uint8_t *)msg, len);
}

void Home_J4(void)
{
	uint8_t j = 3;                      // J3
	uint8_t m = jointToMotor[j];        // Corresponding motor

	//------------- Get average encoder reading ----------------//

	float sum = 0.0f;
	uint8_t count = 0;

	for (int i = 0; i < 20; i++)
	{
		float angle = AS5047P_ReadJoint(j);

		if (angle >= 0.0f)
		{
			sum += angle;
			count++;
		}
	}

	// No valid readings
	if (count == 0)
		return;

	float now = sum / (float) count;


	//------------- First motion : DECREASE to 200° ------------//

	float decreaseDeg;

	if (now >= 200.0f)
	{
		decreaseDeg = now - 200.0f;
	}
	else
	{
		decreaseDeg = now + (360.0f - 200.0f);
	}


	if (fabsf(decreaseDeg) >= 1.0f)
	{
		int32_t step1 = (int32_t) lroundf(
				motors[m].encStepSign *
				(-decreaseDeg) *
				pulsesPerEncRev[j] /
				360.0f);

		int32_t stepsMotor[6] = { 0 };

		stepsMotor[m] = step1;

		motors[m].position = 0;
		motors[m].target = 0;

		Stepper_MoveAll(stepsMotor);

		while (Stepper_AnyMoving())
		{
		}

		HAL_Delay(100);
	}


	//------------- Read encoder AGAIN -------------------------//

	sum = 0.0f;
	count = 0;

	for (int i = 0; i < 20; i++)
	{
		float angle = AS5047P_ReadJoint(j);

		if (angle >= 0.0f)
		{
			sum += angle;
			count++;
		}
	}

	// No valid readings
	if (count == 0)
		return;

	now = sum / (float) count;


	//------------- Second motion : INCREASE to HOME -----------//

	float increaseDeg;

	if (homeAngle[j] >= now)
	{
		increaseDeg = homeAngle[j] - now;
	}
	else
	{
		increaseDeg = (360.0f - now) + homeAngle[j];
	}


	if (fabsf(increaseDeg) >= 1.0f)
	{
		int32_t step2 = (int32_t) lroundf(
				motors[m].encStepSign *
				(increaseDeg) *
				pulsesPerEncRev[j] /
				360.0f);

		int32_t stepsMotor[6] = { 0 };

		stepsMotor[m] = step2;

		motors[m].position = 0;
		motors[m].target = 0;

		Stepper_MoveAll(stepsMotor);

		while (Stepper_AnyMoving())
		{
		}

		HAL_Delay(100);
	}


	//------------- Debug message ------------------------------//

	char msg[250];

	int len = snprintf(msg,
			sizeof(msg),

			"Final Encoder Angle = %.2f\r\n"
			"Home Angle          = %.2f\r\n"
			"Decrease Motion     = %.2f\r\n"
			"Increase Motion     = %.2f\r\n",

			now,
			homeAngle[j],
			decreaseDeg,
			increaseDeg);

	CDC_Transmit_FS((uint8_t*) msg, len);
}

void Home_All(void)
{
	//----------------------------------------------------------
	// J6
	//----------------------------------------------------------

	Home_J6();

	while (Stepper_AnyMoving())
	{
	}

	HAL_Delay(100);


	//----------------------------------------------------------
	// J5
	//----------------------------------------------------------

	Home_J5();

	while (Stepper_AnyMoving())
	{
	}

	HAL_Delay(100);


	//----------------------------------------------------------
	// J4
	//----------------------------------------------------------

	Home_J4();

	while (Stepper_AnyMoving())
	{
	}

	HAL_Delay(100);


	//----------------------------------------------------------
	// DONE
	//----------------------------------------------------------

	char msg[] = "\r\nAll joints homed successfully.\r\n";

	CDC_Transmit_FS((uint8_t *)msg, sizeof(msg) - 1);
}

/* Read the encoder on motor m and update its cumulative tick count.
 Safe to call from the TIM6 ISR at 2 kHz (short SPI timeout). */
void Motor_UpdateEncoder(uint8_t m) {
	// find which joint uses this motor, to reach its CS pin
	int8_t j = -1;
	for (uint8_t k = 0; k < 6; k++)
		if (jointToMotor[k] == m) {
			j = k;
			break;
		}
	if (j < 0)
		return;

	uint16_t cmd = 0xFFFF, rx = 0;
	HAL_GPIO_WritePin(encCSPort[j], encCSPin[j], GPIO_PIN_RESET);
	HAL_StatusTypeDef st = HAL_SPI_TransmitReceive(&hspi1, (uint8_t*) &cmd,
			(uint8_t*) &rx, 1, 2); // 2ms max
	HAL_GPIO_WritePin(encCSPort[j], encCSPin[j], GPIO_PIN_SET);

	if (st != HAL_OK || (rx & 0x4000))
		return;      // bad read or error flag -> skip
	uint16_t raw = rx & 0x3FFF;

	if (!motorEncInit[m]) {
		motorEncRaw[m] = raw;
		motorEncInit[m] = 1;
		return;
	}

	int32_t d = (int32_t) raw - (int32_t) motorEncRaw[m];
	if (d > 8192)
		d -= 16384;
	if (d < -8192)
		d += 16384;
	motorEncTicks[m] += d;
	motorEncRaw[m] = raw;
}

/* Configure TIM1 for servo use: 1 us tick, 20 ms (50 Hz) period, start CH2 */
void Gripper_Init(void) {
	uint32_t timClk = HAL_RCC_GetPCLK2Freq() * 2;      // TIM1 is on APB2

	__HAL_TIM_SET_PRESCALER(&htim1, (timClk / 1000000u) - 1);  // 1 MHz tick
	__HAL_TIM_SET_AUTORELOAD(&htim1, 20000 - 1);               // 20 ms frame

	htim1.Instance->EGR = TIM_EGR_UG;
	HAL_TIM_PWM_Start(&htim1, TIM_CHANNEL_3);

//	__HAL_TIM_MOE_ENABLE(&htim1);
}

/* Set servo pulse width in microseconds (typical range 1000-2000) */
static void Gripper_SetPulse(uint16_t us) {
	__HAL_TIM_SET_COMPARE(&htim1, TIM_CHANNEL_3, us);
}

void Gripper_Open(void) {
	Gripper_SetPulse(930);
}   // tune this value
void Gripper_Close(void) {
	Gripper_SetPulse(1100);
}   // tune this value   // tune this value

/* Read raw 14-bit count for joint j. Returns 0xFFFF on error. */
uint16_t AS5047P_ReadRaw(uint8_t j) {
	uint16_t cmd = 0xFFFF, rx = 0;
	for (int attempt = 0; attempt < 3; attempt++) {
		HAL_GPIO_WritePin(encCSPort[j], encCSPin[j], GPIO_PIN_RESET);
		HAL_SPI_TransmitReceive(&hspi1, (uint8_t*) &cmd, (uint8_t*) &rx, 1,
				100);
		HAL_GPIO_WritePin(encCSPort[j], encCSPin[j], GPIO_PIN_SET);
		if (!(rx & 0x4000))
			return (rx & 0x3FFF);
		AS5047P_ClearErrorCS(j);
	}
	return 0xFFFF;
}

//uint16_t AS5047P_ReadRaw(uint8_t j)
//{
//	uint16_t angleCmd = 0x3FFF;
//	uint16_t nopCmd = 0x0000;
//
//	uint16_t rx;
//
//	/* Request the ANGLE register */
//	AS5047P_SPITransfer(j, angleCmd);
//
//	/* Read the result */
//	rx = AS5047P_SPITransfer(j, nopCmd);
//
//	/* Check the error flag */
//	if (rx & 0x4000)
//	{
//		AS5047P_ClearErrorCS(j);
//		return 0xFFFF;
//	}
//
//	return (rx & 0x3FFF);
//}

/* Update cumulative signed tick counter for joint j (handles 0/16384 wrap).
 +ve = increasing raw count, -ve = decreasing. */
void Encoder_UpdateTicks(uint8_t j) {
	uint16_t raw = AS5047P_ReadRaw(j);
	if (raw == 0xFFFF)
		return;                 // bad read, skip

	if (!encInit[j]) {
		encRawPrev[j] = raw;
		encInit[j] = 1;
		return;
	}

	int32_t d = (int32_t) raw - (int32_t) encRawPrev[j];
	if (d > 8192)
		d -= 16384;                 // wrapped downward through 0
	if (d < -8192)
		d += 16384;                 // wrapped upward through max
	encTicks[j] += d;
	encRawPrev[j] = raw;
}

void AS5047P_ClearErrorCS(uint8_t j) {
	uint16_t cmd = 0x4001, rx;
	HAL_GPIO_WritePin(encCSPort[j], encCSPin[j], GPIO_PIN_RESET);
	HAL_SPI_TransmitReceive(&hspi1, (uint8_t*) &cmd, (uint8_t*) &rx, 1, 100);
	HAL_GPIO_WritePin(encCSPort[j], encCSPin[j], GPIO_PIN_SET);
	HAL_Delay(1);
	cmd = 0xFFFF;
	HAL_GPIO_WritePin(encCSPort[j], encCSPin[j], GPIO_PIN_RESET);
	HAL_SPI_TransmitReceive(&hspi1, (uint8_t*) &cmd, (uint8_t*) &rx, 1, 100);
	HAL_GPIO_WritePin(encCSPort[j], encCSPin[j], GPIO_PIN_SET);
}

///* Read encoder for joint j (0..5). Returns degrees, or -1 on error. */
//float AS5047P_ReadJoint(uint8_t j) {
//	uint16_t cmd = 0xFFFF, rx = 0;
//	for (int attempt = 0; attempt < 3; attempt++) {
//		HAL_GPIO_WritePin(encCSPort[j], encCSPin[j], GPIO_PIN_RESET);
//		HAL_SPI_TransmitReceive(&hspi1, (uint8_t*) &cmd, (uint8_t*) &rx, 1,
//				100);
//		HAL_GPIO_WritePin(encCSPort[j], encCSPin[j], GPIO_PIN_SET);
//
//		if (!(rx & 0x4000))
//			return ((rx & 0x3FFF) * 360.0f) / 16384.0f;
//
//		AS5047P_ClearErrorCS(j);
//	}
//	return -1.0f;
//}

static uint16_t AS5047P_SPITransfer(uint8_t j, uint16_t tx) {
	uint16_t rx = 0;

	HAL_GPIO_WritePin(encCSPort[j], encCSPin[j], GPIO_PIN_RESET);

	HAL_SPI_TransmitReceive(&hspi1, (uint8_t*) &tx, (uint8_t*) &rx, 1, 100);

	HAL_GPIO_WritePin(encCSPort[j], encCSPin[j], GPIO_PIN_SET);

	return rx;
}
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

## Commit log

2026-07-12 Add IK simulation (MATLAB) with project config
    - Add inverse kinematics simulation under "IK Simulation MATLAB/"
    - Add .gitignore for MATLAB/Simulink artifacts and OS junk
    - Add REQUIREMENTS.txt documenting MATLAB release and toolboxes
    [Part1.STL, Part1_Default_sldprt.STEP, Part2.STL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]
2026-07-14 Add IK pipeline, interactive tool, XYZ streaming, and lock demos
    MATLAB/Simscape inverse-kinematics workflow for the 6-DOF arm, from
    model import through hardware streaming and marketing demos.
    Core IK:
    - Import the corrected Simscape Multibody model to a rigidBodyTree
    (importrobot) with real joint limits, including the 180-deg-centered
    bands on J3 and J5.
    - inverseKinematics solver: target XYZ -> six joint angles, with a
    forward-kinematics check confirming the tip reaches the target.
    Interactive & command tools:
    - armIK.m: live X/Y/Z slider tool with real-time IK solve, joint-angle
    readout, and a smooth quintic-blend Play button (skeleton view).
    - goToXYZ.m: solves IK for a target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
2026-07-16 Add PCB schematics and Gerber files for arm control board
    Hardware design files for the NeuralNexusArm main control PCB.
    Added:
    - Schematics (PDF + source) for the STM32H743VITx control board
    - Gerber files and drill data for fabrication
    Board scope:
    - STM32H743VITx (WeAct MiniSTM32H743) carrier and breakout
    - Step/dir/enable routing for M1-M6
    - M1-M3: open-drain outputs for common-anode CL57T / DM542 drivers
    - M4-M6: 3.3V push-pull to TMC2209 drivers
    - 3.3V logic rail via ST1L05 LDO (5V in, 1.3A)
    - USB CDC and SPI headers (SPI reserved for AS5047P encoders, Phase 4)
    Known issue:
    - ST1L05 LDO failed short (3.3V-GND) on first power-up in the main
    electronics compartment. Suspected in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
2026-07-21 Add recorded motion sequences and IK simulation sequences
    - Added recorded motion sequences that replay through the Simscape simulation
    - Added IK-driven simulation sequences (chained pose execution via inverseKinematics)
    - Sequences stream six joint angles over USB serial to animate the model and drive the physical arm in sync
2026-07-23 Enhance README with computer vision details
    Added detailed sections on computer vision, object detection, and camera calibration to the README.
2026-07-23 Add the CodeBase
    [NeuralNexusArm1.0 Debug.cfg]
2026-07-23 Add gerber files
2026-07-23 Add MCU gerber
2026-07-23 Add Schematic files
2026-07-24 Add PCB badge for Altium Designer
    Added PCB badge to the README for Altium Designer.

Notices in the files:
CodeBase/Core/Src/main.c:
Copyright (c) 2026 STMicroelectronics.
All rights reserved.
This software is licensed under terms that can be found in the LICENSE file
